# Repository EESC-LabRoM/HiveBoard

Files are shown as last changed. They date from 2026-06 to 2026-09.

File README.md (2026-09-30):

# HiveBoard

<p align="center">
  <picture>
    <source media="(prefers-color-scheme: dark)" srcset="Images/HIVEBOARD_logo_dark.png">
    <source media="(prefers-color-scheme: light)" srcset="Images/HIVEBOARD_logo_light.png">
    HiveBoard logo
  </picture>
</p>

[Project website](https://hiveboard-bench.github.io) · [Documentation](https://hiveboard-bench.github.io/hivedocs/) · [Evaluation Runner](https://hiveboard-bench.github.io/hivedocs/benchmark/evaluation-runner) · [Demonstration video](https://youtu.be/kaYB_Oc64nA)

HiveBoard is a modular, 3D-printable benchmark of industrial mechanisms for robotic and prosthetic manipulation. Its attachments require constrained motions such as valve rotation, threading, key insertion, and drawer opening and closing.

A seven-cell honeycomb base accepts interchangeable attachments through a shared press-fit interface. The same board and protocol can be used to evaluate robot grippers, dexterous hands, teleoperated manipulators, and worn prosthetic hands.

This repository contains the printable parts, CAD models, articulated simulation assets, evaluation protocol, and trial templates.

## Getting started

1. Read the [printing guide](https://hiveboard-bench.github.io/hivedocs/hardware/printing) and the recommended settings below.
2. Print one honeycomb cell and one attachment base to check the press fit before printing the full set.
3. [Assemble and mount the board](https://hiveboard-bench.github.io/hivedocs/hardware/assembly). Check that each mechanism moves freely and each attachment remains seated.
4. Read the [evaluation protocol](Documentation/PROTOCOL.md), including familiarization, success criteria, timeouts, and counting conventions.
5. Record **five trials for each of the 13 conditions (65 trials total)** using the [Evaluation Runner](https://hiveboard-bench.github.io/hivedocs/benchmark/evaluation-runner) or the [CSV](Documentation/trials.csv) / [XLSX](Documentation/trials.xlsx) template.

The documentation and Evaluation Runner are maintained in [`docs/` in the project website repository](https://github.com/hiveboard-bench/hiveboard-bench.github.io/tree/main/docs).

## Board and attachments

<p align="center">
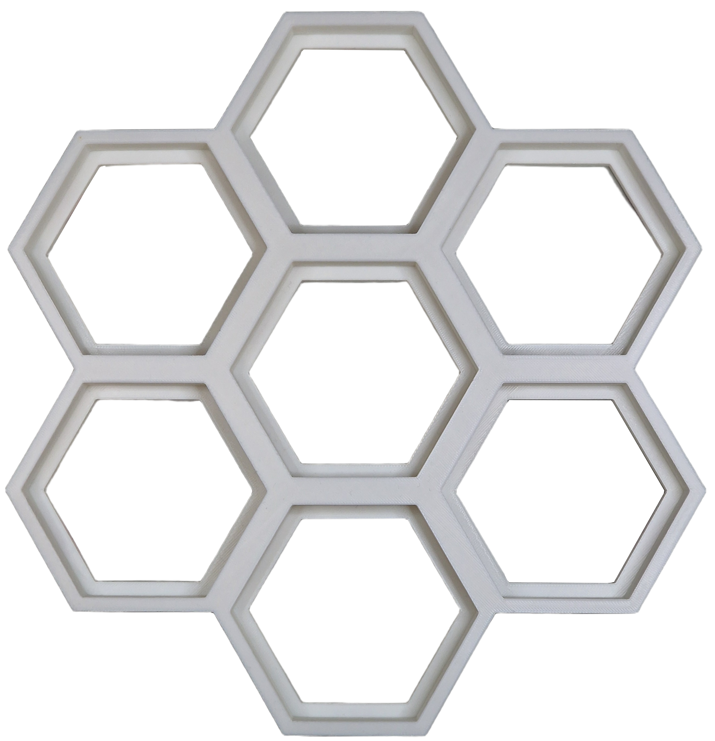
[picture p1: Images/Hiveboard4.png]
HiveBoard honeycomb base with mounted mechanisms
  
</p>

HiveBoard has 12 attachment designs evaluated in 13 conditions. The ball valve is evaluated without and with a friction ring, giving two conditions for the same attachment design. Attachments share the same mounting geometry. The shock absorber occupies two adjacent cells. The ball valve is evaluated in two configurations: without a friction ring and with a ring fitted.

<p align="center">
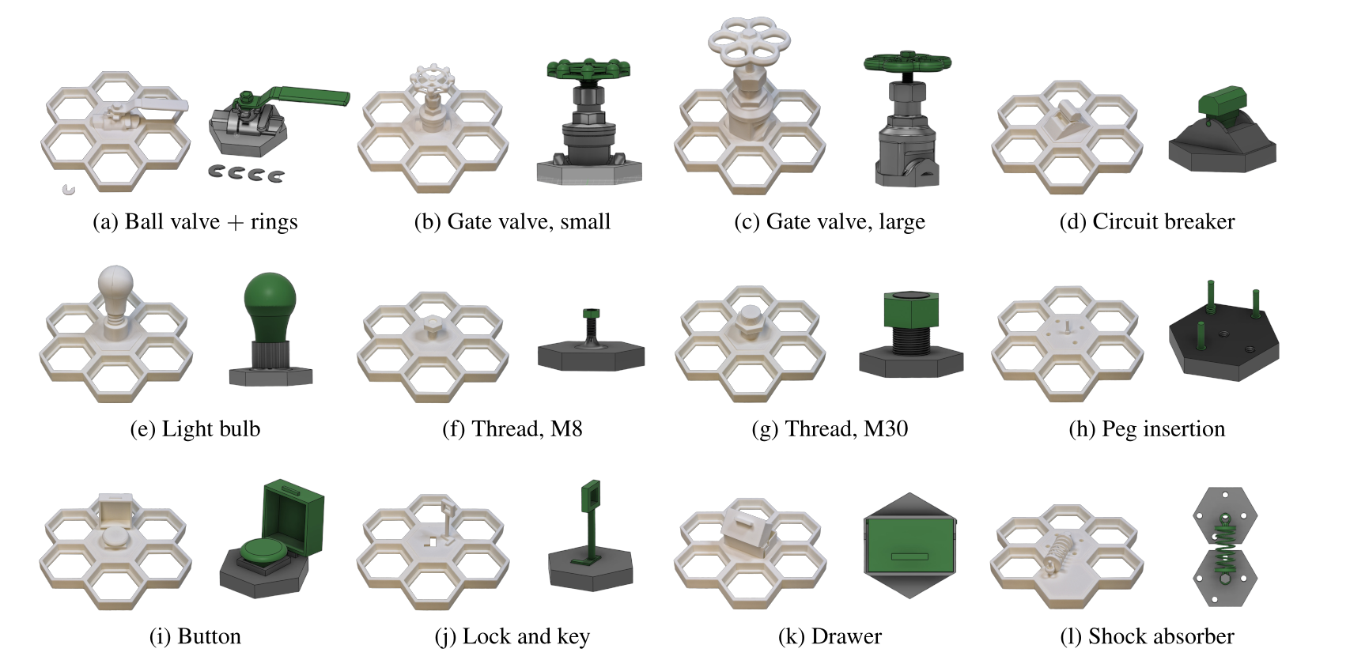
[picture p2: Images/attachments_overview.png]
HiveBoard mechanisms shown on the base and as individual renders
  
</p>

| Category | Attachment | Task |
|---|---|---|
| Torque | Ball valve | Rotate the lever 90° from closed to open |
| Torque | Ball valve + ring | Complete the same rotation with the ring fitted |
| Torque | Gate valve (small) | Rotate the stem one full turn |
| Torque | Gate valve (large) | Rotate the stem one full turn |
| Torque | Circuit breaker | Move the toggle to the opposite state and hold it |
| Precision | Light bulb | Thread the bulb until seated |
| Precision | Thread (M8) | Thread the bolt along the available length |
| Precision | Thread (M30) | Thread the bolt along the available length |
| Precision | Peg insertion | Align and thread the free 8 mm peg into the socket until seated |
| Composed assembly | Button | Open the cover and press the button |
| Composed assembly | Lock and key | Grasp the key, insert it vertically, and turn it to unlock |
| Composed assembly | Drawer | Grasp the handle, pull the drawer open, and push it closed |
| Composed assembly | Shock absorber | Grasp the loose part, align its hole with the pin, and insert the part fully onto the pin |

The friction-ring accessory includes four rings with different rotational resistance. Record the configuration used. The gate-valve criterion is **one full turn of the stem**; full travel depends on the printed thread pitch. For composed assembly tasks, record the last completed stage as well as the overall outcome.

See [the protocol](Documentation/PROTOCOL.md) for timeouts and stage definitions, and [Terminology](Documentation/TERMINOLOGY.md) for task names and trial identifiers.

## ArUco cell

The optional [ArUco cell](CAD/ArUco%20Cell/) provides a visual reference for board localization and alignment between physical and simulated scenes. Print the base in white PLA and the marker insert in black PLA, fit the parts together, and optionally glue the mating surfaces. The folder includes the two printable parts, an assembled model, a CAD reference image, and printing and assembly instructions.

## Recommended 3D printing settings

Use PLA and a consumer-grade FDM printer. A **300 × 300 mm build area** accommodates the complete honeycomb base without splitting it. Thread test pieces are included in [`STL/Threads/`](STL/Threads/) for checking print tolerances before producing the complete mechanisms.

Detailed assembly and printing instructions are available in the [attachment-specific printing guide (PDF)](https://github.com/user-attachments/files/29721347/HiveBoard.-.Module-Specific.Instructions.1.pdf).

### PLA profile

| Setting | Value |
|---|---|
| Material | PLA |
| Nozzle diameter | 0.4 mm |
| Layer height | 0.20 mm |
| Wall count | 4 |
| Top / bottom layers | 5 / 5 |
| Infill | 15–30%, according to part type |
| Print speed | 50 mm/s |
| Nozzle temperature | 200–220 °C |
| Bed temperature | 50–60 °C |
| Cooling fan | 100% |
| Supports | Only where required |
| Bed adhesion | Skirt or brim |

### Infill

| Part type | Infill |
|---|---|
| Base structure | 20% |
| Mechanical parts | 25% |
| Torque components | 30% |
| Threads | 25% |
| Decorative covers | 15% |

### Orientation

| Component | Orientation |
|---|---|
| Threads and screws | Vertical |
| Nuts | Flat |
| Valves | Handle up |
| Drawer | Largest face on the bed |
| Pegs | Vertical |
| Shock absorber parts | Sideways |

Remove stringing and support material, check mating surfaces, and test the threads by hand. Record sanding, lubrication, and dimensional adjustments with the evaluation. Inspect attachment seating before each session and after any displacement or damage.

## Evaluation and trial records

A complete evaluation contains **65 recorded trials**, including separate five-trial blocks for the two ball-valve configurations. Keep the platform configuration and control interface consistent within the recorded trial blocks.

For each trial, record:

- outcome: `success`, `fail`, `timeout`, or `safety_stop`;
- completion time in decimal seconds, for successful trials only;
- attempts counted from 1 and regrasps counted from 0;
- prehensile or non-prehensile strategy;
- last completed stage for composed assembly tasks; and
- one dominant failure cause for unsuccessful trials.

Use [`HOW_TO_FILL_TRIALS.md`](Documentation/HOW_TO_FILL_TRIALS.md) for the column definitions and allowed failure causes. Preserve trials involving broken or displaced parts and describe the event in `notes`.

### Browser-based evaluation

The [Evaluation Runner](https://hiveboard-bench.github.io/hivedocs/benchmark/evaluation-runner) displays task instructions and example videos, provides a countdown and timer, and exports the trial records. Begin the first commanded task motion when the countdown reaches zero. The evaluator determines whether the success criterion has been met.

Record every trial with an external camera, keeping the board, end-effector, and final task state visible. Once all 65 trial entries and required setup details are complete, the runner generates a results ZIP with the CSV, platform description, manifest, session backup, and recording filenames.

Attach the setup photograph in the runner or add it to the extracted ZIP as `setup.jpg`. Add the 65 recordings to `videos/` using the generated filenames. The runner saves records locally and does not upload submissions to the organizers.

## Simulation assets

[`Simulation/`](Simulation/) contains URDF and USD assets, visual and collision meshes, joint definitions, and nominal physical properties. The mechanisms use revolute, continuous, and prismatic joints. Threaded motion is represented by coupled rotation and translation; drawer, lock, and shock-absorber articulation is provided in the USD assets.

Friction, mass, and inertia are nominal values. Check joint motion, collision geometry, and physical parameters in the simulator used for an experiment, and report any parameter overrides.

Isaac Lab environments and training code are maintained separately in [EESC-LabRoM/isaaclab-hiveboard](https://github.com/EESC-LabRoM/isaaclab-hiveboard). See the [simulation documentation](https://hiveboard-bench.github.io/hivedocs/simulation/assets) for asset usage and the [Isaac Lab guide](https://hiveboard-bench.github.io/hivedocs/simulation/isaac-lab) for installation and commands.

## Reported evaluations

HiveBoard has been evaluated at four laboratories using:

| Platform | Control |
|---|---|
| Boston Dynamics Spot with Spot Arm | Native tablet teleoperation |
| LeRobot SO-101 | Leader–follower teleoperation |
| ANYbotics ANYmal with DynaArm | Virtual-reality controllers |
| Macao prosthetic hand | Worn on the operator's forearm |

Each platform ran all 65 trials. Results and demonstration videos are available on the [project website](https://hiveboard-bench.github.io). The original trial logs are held by the contributing laboratories and are not distributed in this repository.

## Repository contents

| Directory | Contents |
|---|---|
| [`STL/`](STL/) | Printable parts and thread test pieces |
| [`CAD/`](CAD/) | Source geometry and mesh exports |
| [`Simulation/`](Simulation/) | Articulated assets and meshes |
| [`Documentation/`](Documentation/) | Protocol, logging instructions, and CSV/XLSX templates |
| [`Images/`](Images/) | Photographs, logos, and renders |

For a new attachment, reuse the mounting interface and document its initial state, success criterion, timeout, and reset procedure. See [Adding an attachment](https://hiveboard-bench.github.io/hivedocs/guides/new-attachment).

## Citation

If you use HiveBoard in your research, cite the project paper:

```bibtex
@article{hiveboard2026,
  title   = {HiveBoard: An Open, Modular, 3D-Printed Benchmark of Industrial Mechanisms
             for Robotic and Prosthetic Manipulation},
  author  = {Godoy, Ricardo V. and de Souza, Enzo F. and de Lange, Rudy De-Xin and
             Negri, Juliano and Marsicano, Jo\~{a}o A. and van Halst, Victor and
             Elanjimattathil Vijayan, Aravind and Capezzuto, Gianluca and
             Angarola, Matheus P. and Tommaselli, Felipe A. G. and Milazzo, Giuseppe and Baptista, Rafael R. and
              van Berge, Meiko Adriana and Bezerra, Ranulfo and Lahr, Gustavo J. G. and Ferrari Gerez, Lucas and
              Bicchi, Antonio and Becker, Marcelo},
  journal = {Under review},
  year    = {2026},
  url     = {https://github.com/EESC-LabRoM/HiveBoard}
}
```

## License

This project is intended for research, educational, and prototyping purposes.

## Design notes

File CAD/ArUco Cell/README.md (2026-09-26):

# ArUco cell

The ArUco cell provides a visual reference for locating HiveBoard in camera images. It can support board-pose estimation and alignment of physical and simulated scenes once the marker dimensions and its placement on the board are known.

The cell has two interlocking parts, printed separately in white and black PLA. The white base forms the hexagonal support and the white regions of the marker. The black insert completes the marker pattern. The parts fit together and can be glued after checking their alignment.

This is an optional accessory. The benchmark evaluation remains 13 conditions with five trials per condition.

## Files

| File | Purpose | Material |
|---|---|---|
| [aruco_cell_base_white.obj](aruco_cell_base_white.obj) | Hexagonal base and white marker regions | White PLA |
| [aruco_cell_marker_black.obj](aruco_cell_marker_black.obj) | Black marker insert | Black PLA |
| [aruco_cell_assembly.obj](aruco_cell_assembly.obj) | Assembled reference with both parts in position | White and black |

Keep each OBJ beside its matching MTL file. The MTL files assign the display colors. Choose the corresponding filament when slicing each physical part. The assembly OBJ shows the intended fit and orientation.

These are mesh exports. Vertex positions, faces, and exported scale are preserved from the supplied files. Filenames, object groups, and material names have been standardized in English, and the OBJ material links have been updated.

## Printing and assembly

1. Import the white base and black insert into the slicer as separate parts. Set the import units to centimetres, or apply a scale factor of 10 if the slicer interprets OBJ coordinates as millimetres. Apply the same scale to both parts and verify an assembled width of 88.1 mm.
2. Print the base in white PLA and the insert in black PLA. Use the repository's recommended PLA profile as a starting point and inspect the mating surfaces for stringing or excess material.
3. Fit the two parts together in the orientation shown in the assembly model. Check that the marker pattern is complete and the insert is fully seated.
4. If permanent assembly is required, apply a small amount of PLA-compatible adhesive to the mating surfaces. Keep adhesive away from the visible marker face. Let it cure before mounting.
5. Seat the assembled cell in the honeycomb base and check that it remains fixed. Keep the marker visible to the camera during use.

## Dimensions and marker configuration

The designer confirmed an overall width of **88.1 mm**. The OBJ coordinates therefore correspond to centimetres. The files retain their original coordinates.

| Dimension | Nominal size |
|---|---|
| Assembly bounding box | 88.1 × 76.297 × 22.0 mm |
| Outer black marker square | 47.505 mm per side |

For a millimetre-based importer, multiply the OBJ coordinates by 10. For a metre-based simulator, multiply them by 0.01. Check the imported dimensions before printing or using the model in simulation.

The marker was generated with [chev.me/arucogen](https://chev.me/arucogen/) using **4×4 (50, 100, 250, 1000)** and **marker ID 0**. Configure the detector with **OpenCV `DICT_4X4_50`, ID `0`**. This ID has the same bit pattern in `DICT_4X4_50`, `DICT_4X4_100`, `DICT_4X4_250`, and `DICT_4X4_1000`, which share the same underlying marker list in [OpenCV](https://github.com/opencv/opencv/blob/4.x/modules/objdetect/src/aruco/aruco_dictionary.cpp). Verify detection on the printed part. For pose estimation, measure the square marker side from the outer edges of its black border and use calibrated camera parameters. Record the marker's location and orientation relative to the board so that its estimated pose can be converted to a board pose.

Record the dictionary, marker ID, measured marker side length, model scale, and marker-to-board transform with each setup. Detection accuracy and physical-to-simulation alignment need to be measured in the intended camera and lighting configuration.

See the [OpenCV ArUco detection documentation](https://docs.opencv.org/4.x/d5/dae/tutorial_aruco_detection.html) for dictionary selection, detection, and pose estimation.

## Assembly model

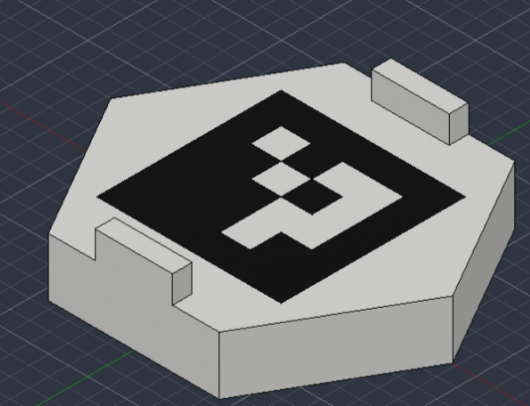
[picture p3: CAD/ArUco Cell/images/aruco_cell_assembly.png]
CAD view of the white hexagonal base and black marker insert


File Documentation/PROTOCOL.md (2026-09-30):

# HiveBoard: Data Collection Protocol

Use [Terminology](TERMINOLOGY.md) to match task names to trial identifiers and existing file names.

This document specifies the data each collaborating laboratory collects to validate HiveBoard, the modular dexterity board. The activity is operator-driven trials, robot-side performance characterization across attachments. Operators may control the manipulation system through a teleoperated arm or through a wearable interface or exoskeleton that drives a gripper or hand directly.

The objective is to demonstrate that the board is functional, reproducible, and discriminative across attachments and platforms. The protocol does not rank platforms against each other and does not characterize control interfaces or operators.

**Project resources:**
- Repository (STL, CAD, simulation assets, this protocol, trial logging template): https://github.com/EESC-LabRoM/HiveBoard
- Project page: https://hiveboard-bench.github.io
- Demonstration video (board walk-through and example trials): https://youtu.be/kaYB_Oc64nA

---

## 1. Materials

- One printed HiveBoard base.
- One full set of attachments across all three categories (torque, precision, composed assembly), including the four-piece friction ring accessory set for the ball valve.
- A manipulation system, consisting of an end-effector (gripper or hand) plus a control interface. The control interface may be:
  - a teleoperated robotic arm with a standard interface (e.g., SpaceMouse, leader arm, VR controller), or
  - a wearable interface or exoskeleton driving the end-effector directly.

## 2. Printing Specifications

The canonical print profile lives in the project README. Summary, for convenience:

- **Material:** PLA, 1.75 mm filament.
- **Nozzle:** 0.4 mm.
- **Layer height:** 0.20 mm.
- **Walls:** 4 perimeters.
- **Top / bottom layers:** 5 / 5.
- **Print speed:** 50 mm/s.
- **Nozzle temperature:** 200 to 220 °C.
- **Bed temperature:** 50 to 60 °C.
- **Cooling:** 100%.
- **Adhesion:** skirt or brim.
- **Supports:** only where required.

**Infill, per part type:**

| Part type | Infill |
|---|---|
| Base structure | 20% |
| Mechanical parts | 25% |
| Torque components | 30% |
| Threads | 25% |
| Decorative covers | 15% |

**Print orientation:**

| Component | Orientation |
|---|---|
| Threads / screws | vertical |
| Nuts | flat |
| Valves | handle up |
| Drawer | flat on the largest face |
| Pegs | vertical |
| Shock absorber parts | sideways |

**Post-processing.** Remove stringing and check that mating surfaces seat fully before testing. Minor sanding of threaded surfaces may improve performance when printer calibration produces tight tolerances. If sanding is applied to any attachment, record it in the trial `notes` column.

## 3. Physical Setup

1. Fix the HiveBoard base to a rigid surface within the operator's working volume. The base may be mounted horizontally on a tabletop or vertically on a fixture. State which one in `platform.md`, since a vertical mount changes the approach direction for every attachment and makes press-fit release more likely.
2. Insert the attachments into their designated cells. Each attachment seats by press-fit; verify all attachments are fully seated before starting trials.
3. Position the manipulation system so that all attachments are reachable without base repositioning during a trial.
4. Photograph the setup and store the image as `setup.jpg`.

## 4. Trial Procedure

HiveBoard has 12 attachment designs evaluated in 13 conditions. The ball valve is evaluated without and with a friction ring, giving two conditions for the same attachment design.

For each `(platform, condition)` pair:

1. **Familiarization.** Run unrecorded practice trials until completion times stabilize. Record only after three consecutive practice trials complete within 20% of each other or within the timeout, whichever comes first.
2. **Recorded trials.** Run **5 recorded trials** per condition. The end-effector starts each trial from the same neutral pose for a given platform.
3. **Trial start.** Begin timing when the operator initiates the first commanded motion toward the attachment.
4. **Trial end.** Stop timing when the success criterion is met, when a safety event occurs, or when the timeout is reached.
5. **Reset.** Return the attachment to its starting state between trials. Re-seat the attachment in its cell if displaced.

The ball valve is run as two separate sets of 5 trials: once without the friction ring (`valve_ball`) and once with the ring fitted (`valve_ball_ring`).

No scripted assistance, replanning, or per-trial parameter tuning is permitted during recorded trials. A restarted approach within a trial counts as another attempt. Count a regrasp only when the end-effector releases the part and grasps it again. The initial grasp is not a regrasp. Attempts and regrasps are separate counts; neither starts a new trial.

6. **Broken or displaced parts.** If a printed part breaks or leaves its cell during a trial, record the trial as it stood, describe the damage in the `notes` column, and reprint or reseat the part before continuing. Do not silently rerun the trial. Printed mechanisms have failed under jittering or high-gain command signals in previous sessions, and those events are part of the result.

## 5. Per-Attachment Success Criteria and Timeouts

**Torque category**

| Attachment | Success criterion | Timeout |
|---|---|---|
| Ball valve | Handle rotated 90° from closed to open | 60 s |
| Ball valve + ring | Handle rotated 90° from closed to open with the ring fitted | 90 s |
| Gate valve (small) | Stem rotated one full turn from the closed position | 90 s |
| Gate valve (large) | Stem rotated one full turn from the closed position | 120 s |
| Circuit breaker | Toggle moved from one state to the other and held | 60 s |

**Precision category**

| Attachment | Success criterion | Timeout |
|---|---|---|
| Light bulb | Bulb fully threaded until seated | 120 s |
| Thread (M8) | Bolt fully threaded along available length | 120 s |
| Thread (M30) | Bolt fully threaded along available length | 120 s |
| Peg insertion | Free peg threaded into the empty socket until it seats | 120 s |

The gate valve criterion is one full turn of the stem, not travel from fully closed to fully open. A platform that can turn the stem once can repeat the motion, and the number of turns to full travel depends on the printed thread pitch, so full travel is not comparable across prints. If your trials ran to full travel, report the time to the first complete turn and note it in the `notes` column.

**Composed assembly category (stage-wise scoring)**

These attachments are scored at sub-task granularity. Record the last completed stage within the timeout.

| Attachment | Stages | Timeout |
|---|---|---|
| Button | (1) Open the cover (2) Press the button until actuation | 60 s |
| Lock and key | (1) Grasp key (2) Insert key vertically (3) Rotate to unlock | 180 s |
| Drawer | (1) Grasp handle (2) Pull open (3) Push closed | 120 s |
| Shock absorber | (1) Grasp the loose part (2) Align its hole with the pin (3) Insert the part fully onto the pin | 180 s |

A trial is a full success only if all stages complete within the timeout. Partial completions are recorded by their last completed stage in the `stage_reached` column.

## 6. Data to Log per Trial

Each trial fills one row of `trials.csv` (template provided alongside this protocol). See `HOW_TO_FILL_TRIALS.md` for column-by-column instructions.

### Logging conventions

These conventions exist because logs returned from different laboratories have disagreed on all five points, which leaves the columns incomparable until they are reconciled by hand.

| Column | Convention |
|---|---|
| `completion_time_s` | Decimal seconds, as a plain number. Not milliseconds, not a text string, not a clock time, not a date. Write `12.9`, not `12923`, not `12.9 s`, not `timeout`. Leave the cell empty when the outcome is not `success`. |
| `n_attempts` | Discrete attempts at the task within the trial, counted from 1. An attempt ends when the operator abandons the current approach and starts over. Corrective motions inside one continuous approach are not separate attempts. |
| `n_regrasps` | Times the end-effector released the part and closed on it again, counted from 0. A trial with one grasp and no release is 0. A platform that cannot regrasp records 0. |
| `stage_reached` | The number of the last stage the trial completed, from 0 to 3. A successful trial reaches its final stage. A trial that never completed stage 1 is 0. Fill only for the composed assembly attachments. |
| `strategy` | `prehensile` when the end-effector closed around the part and held it, `non_prehensile` when the part was driven by pushing or pressing, or by a finger or jaw entered into an opening without an enclosing grip. |

Fill `n_attempts`, `n_regrasps`, and `strategy` on unsuccessful trials as well. A failed trial still had attempts, and how a platform approached a part it could not complete is as informative as how it approached one it could.

For every trial whose outcome is `fail`, `timeout`, or `safety_stop`, record the dominant failure cause in the `failure_cause` column using this closed vocabulary:

| Cause | Meaning |
|---|---|
| `grasp_geometry` | The end-effector cannot engage the part in a stable grasp (shape, size, or access mismatch). |
| `kinematic_limit` | The platform cannot produce the motion the task requires (e.g., clean rotation about an axis). |
| `perception` | The operator could not see or judge alignment well enough to complete the task. |
| `slip` | A grasp was acquired but lost during execution. |
| `force_limit` | The grasp or actuation force the platform can produce is insufficient for the task, even though the grasp and the motion are otherwise correct (e.g., holding a screw against thread friction). |
| `control_precision` | The available control resolution was too coarse for the clearance or force the task requires. |
| `other` | None of the above; describe in `notes`. Use this for a trial ended by a broken printed part. |

Pick the single dominant cause per trial. Leave the column blank on `success` rows. The closed vocabulary is what makes failure modes comparable across laboratories, so use `other` plus a note only when nothing else fits.

Alongside `trials.csv`, each lab provides:

- `setup.jpg`, photograph of the physical setup.
- `platform.md`, short description of the manipulation system: end-effector (gripper or hand), control interface (teleoperated arm or wearable), board mounting orientation, and any relevant control mode or calibration notes.

## 7. Submission

Each collaborating lab returns a single archive containing:

- `trials.csv`
- `setup.jpg`
- `platform.md`

### Reproducibility checklist

- [ ] All attachments printed with the specified PLA profile and per-part-type infill.
- [ ] Each attachment seats fully in the base before trials begin.
- [ ] Familiarization completed for every attachment before recording.
- [ ] 5 recorded trials per condition, all logged in `trials.csv`. The ball valve appears twice, once without the friction ring and once with it.
- [ ] Timeouts enforced as specified.
- [ ] `failure_cause` filled from the closed vocabulary for every `fail`, `timeout`, and `safety_stop` row.
- [ ] `completion_time_s` in decimal seconds on every `success` row, and empty everywhere else.
- [ ] `n_attempts` counted from 1 and `n_regrasps` from 0, on failed rows as well as successful ones.
- [ ] `strategy` filled on every row.
- [ ] Any broken or reseated part described in `notes`.
- [ ] `setup.jpg` and `platform.md` included, with the board mounting orientation stated.
- [ ] No operator names or identifiers in any field.

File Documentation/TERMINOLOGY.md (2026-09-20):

# Terminology

Use the task names from Table 2 of the HiveBoard paper in instructions, figures, result tables, and interfaces. The table below maps those names to the identifiers used in trial records.

## Task names and identifiers

| Task name | Trial identifier (`attachment_id`) | Category |
|---|---|---|
| Ball valve | `valve_ball` | Torque |
| Ball valve + ring | `valve_ball_ring` | Torque |
| Gate valve (small) | `valve_gate_small` | Torque |
| Gate valve (large) | `valve_gate_large` | Torque |
| Circuit breaker | `circuit_breaker` | Torque |
| Light bulb | `light_bulb` | Precision |
| Thread (M8) | `thread_m8` | Precision |
| Thread (M30) | `thread_m30` | Precision |
| Peg insertion | `peg_insertion` | Precision |
| Button | `button` | Composed assembly |
| Lock and key | `lock` | Composed assembly |
| Drawer | `drawer` | Composed assembly |
| Shock absorber | `shock_absorber` | Composed assembly |

HiveBoard has 12 attachment designs evaluated in 13 conditions. The ball valve is evaluated without and with a friction ring, giving two conditions for the same attachment design. Ball valve + ring is the condition with the ring fitted. Record five trials for each of the 13 conditions, including separate blocks for Ball valve and Ball valve + ring.

The category headings are **Torque-based tasks**, **Precision-based tasks**, and **Composed assembly tasks**. In tables, use **Torque**, **Precision**, and **Composed assembly**. The abbreviation “Assembly” in existing templates and the paper's Table 2 refers to Composed assembly.

## Hardware, tasks, and evaluation

| Term | Meaning |
|---|---|
| Honeycomb base | The structure into which the attachments are mounted. |
| Attachment | A physical mechanism mounted on the base, such as the drawer or a gate valve. |
| Task | The operation performed on an attachment, with a specified starting state and success criterion. |
| Condition | A scored task configuration. The two ball-valve configurations are separate conditions. |
| Trial | One recorded execution of a task, ending at success, failure, timeout, or a safety stop. |
| Platform | The end-effector and the system that positions and commands it. |
| End-effector | The gripper, hand, or other terminal device that interacts with the attachment. |
| Control interface | The interface used to command the platform. Record the control mode or policy separately where relevant. |
| Asset | A digital file or model, such as CAD geometry, a mesh, URDF, or USD. Use “attachment” for the physical mechanism. |
| Attempt | A discrete approach to the task within a trial; count from 1. Abandoning an approach and starting another adds one attempt. |
| Regrasp | A release followed by grasping the part again; count from 0. An initial grasp is not a regrasp. |
| Last completed stage | The highest completed stage of a composed assembly task, recorded as `stage_reached`; 0 means no stage was completed. |
| Dominant failure cause | The single cause recorded in `failure_cause` for an unsuccessful trial. |

## Existing names in files

Older labels and file paths may use the names below. They refer to the same attachments; descriptive details such as the button cover or the threaded peg remain part of the task instructions.

| Existing label or filename term | Task name |
|---|---|
| Ball valve with friction ring | Ball valve + ring |
| Small gate valve; Valve Gate (Small) | Gate valve (small) |
| Large gate valve; Valve Gate (Large) | Gate valve (large) |
| Light bulb socket; light bulb and socket; `Lamp/` | Light bulb |
| M8 threaded fastener; Thread M8 | Thread (M8) |
| M30 threaded fastener; Thread M30 | Thread (M30) |
| Threaded peg insertion; Peg Insertion Plate | Peg insertion |
| Covered button; Hidden Push Button | Button |
| `Key/` | Lock and key |
| Sliding Drawer; `box` in image/video filenames | Drawer |
| `spring` in image/video filenames | Shock absorber |

Keep existing identifiers, paths, and data fields unchanged. For example, `lock` remains the trial identifier for Lock and key, `light_bulb` remains the identifier for Light bulb, and `control_method` remains the runner's stored field for the control interface. The CSV outcome `fail` is displayed as “Failure” in the runner.

Thread (M14) is available in the 3D viewer but is not one of the 13 scored conditions.

See [the protocol](PROTOCOL.md) for task criteria and [the logging instructions](HOW_TO_FILL_TRIALS.md) for counting conventions.

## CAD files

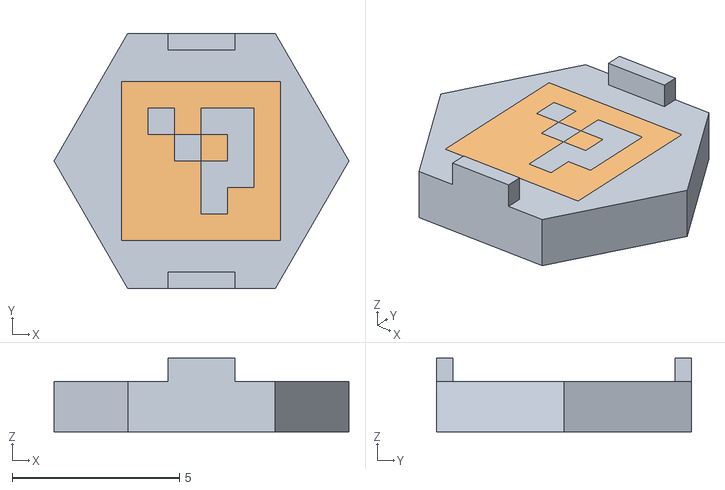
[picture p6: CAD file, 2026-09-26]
CAD/ArUco Cell/aruco_cell_assembly.obj
8.81 x 7.63 x 2.20
aruco_cell_base_white
aruco_cell_marker_black

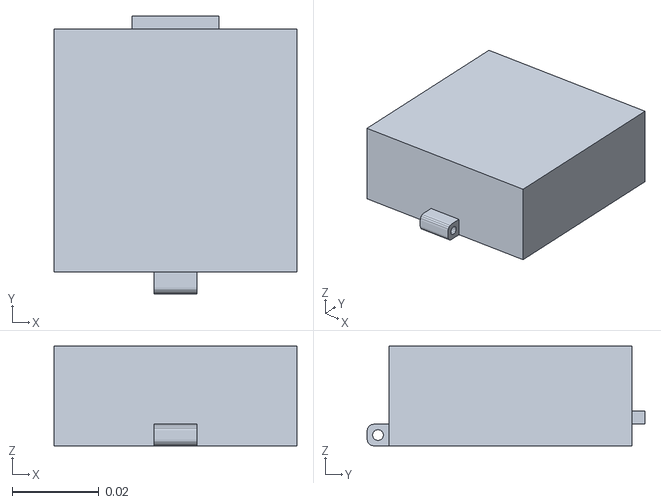
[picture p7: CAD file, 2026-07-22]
Simulation/Button/meshes/tn__Tampa1_dC_Corpo1_Mesh.obj
0.056 x 0.064 x 0.023

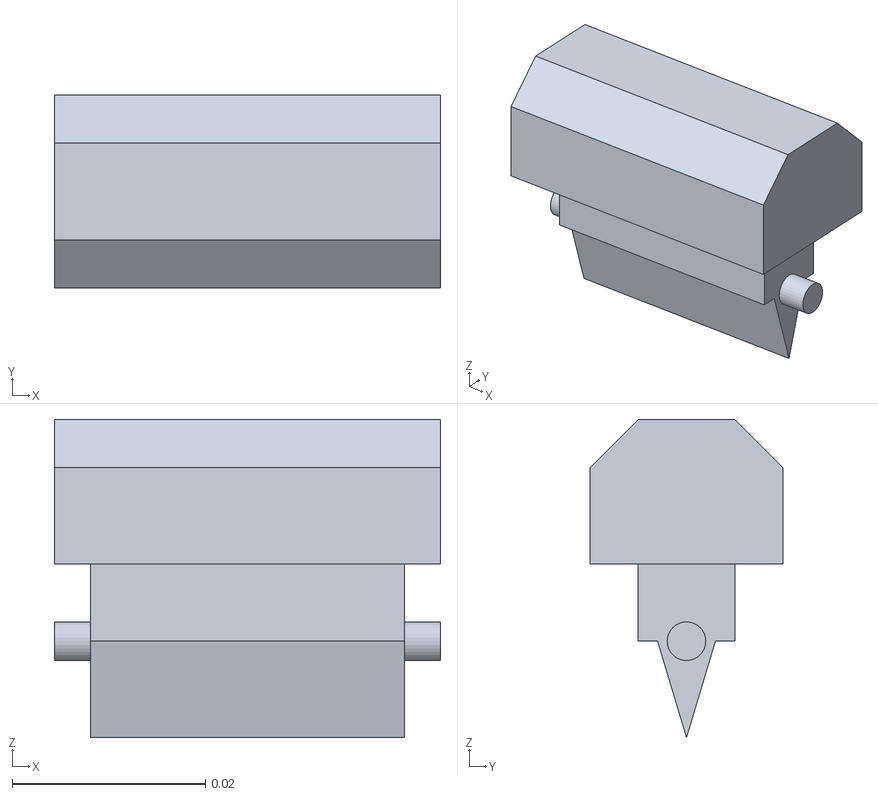
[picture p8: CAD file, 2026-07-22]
Simulation/Circuit Breaker/meshes/tn__Alavanca1_zH_Corpo1_Mesh.obj
0.04 x 0.02 x 0.033

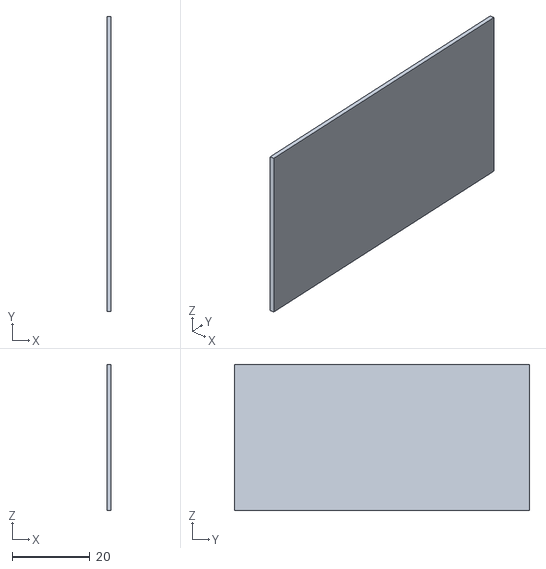
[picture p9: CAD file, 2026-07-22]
Simulation/Drawer/meshes/simple_colliders_Cube_01.obj
1 x 75.7 x 37.6

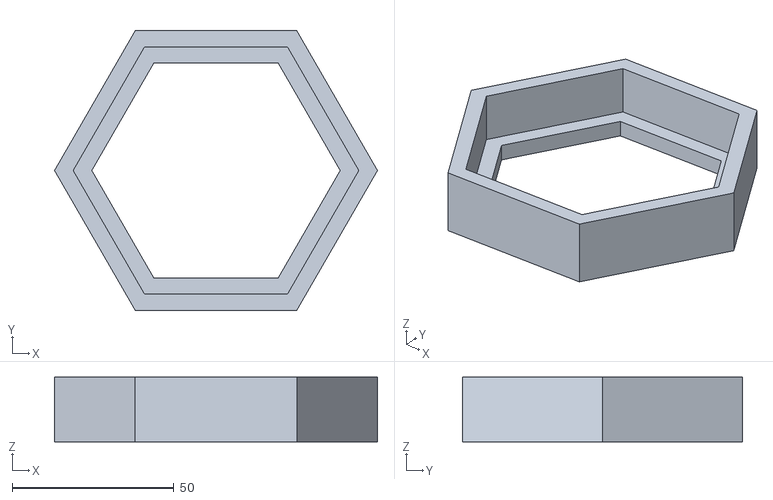
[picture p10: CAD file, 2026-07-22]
Simulation/Honeycomb/meshes/tn__Hexagono_Suporte3_bX0_Corpo1_Mesh.obj
100.0 x 86.6 x 20.0

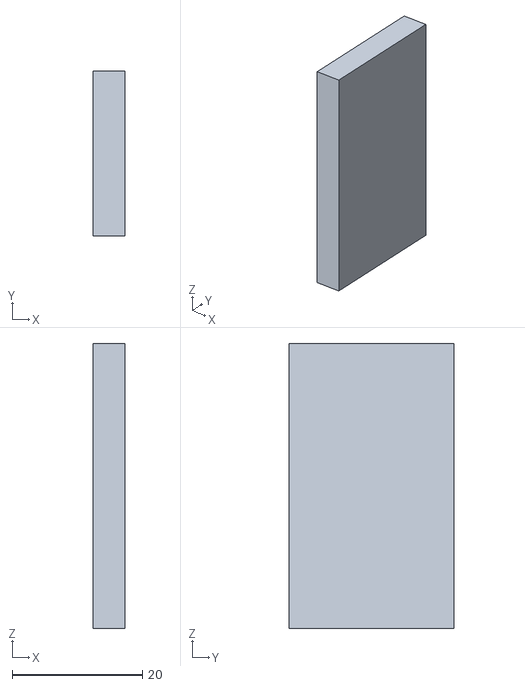
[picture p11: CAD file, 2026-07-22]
Simulation/Key/meshes/Key_Base_pivot_Corpo1_simple_colliders_Cube_01.obj
4.93 x 25.4 x 43.8

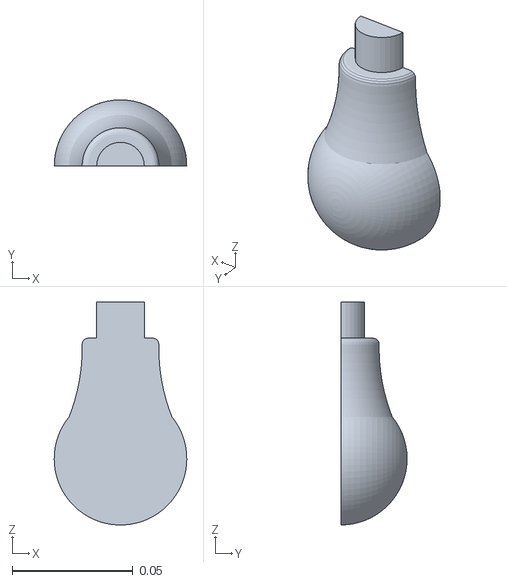
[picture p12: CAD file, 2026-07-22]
Simulation/Lamp/meshes/tn__Corpo11_j7m1J_Mesh.obj
0.055 x 0.0275 x 0.0925

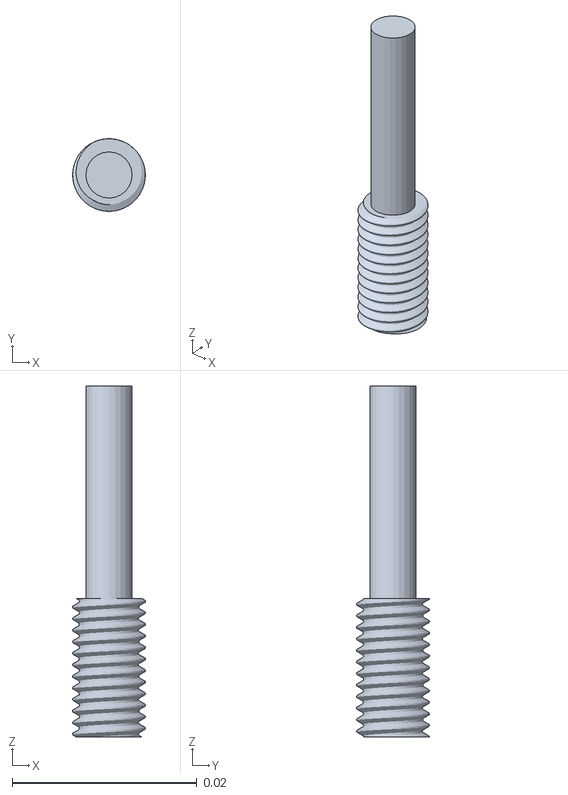
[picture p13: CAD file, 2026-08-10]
Simulation/Peg Insertion/meshes/Al__a_Corpo1.obj
0.00786 x 0.00787 x 0.038

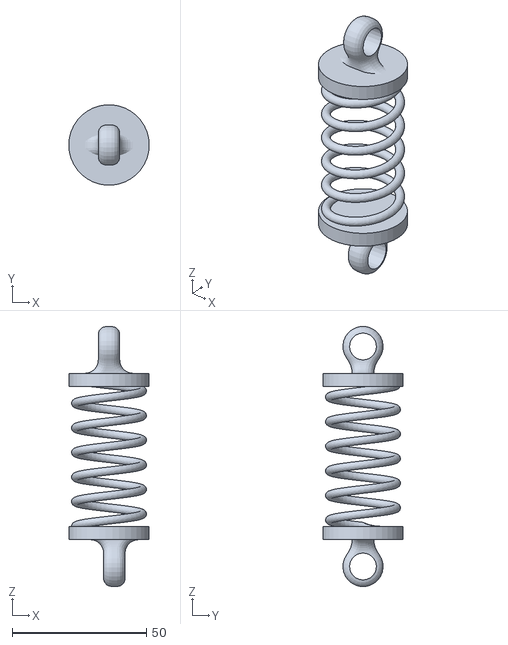
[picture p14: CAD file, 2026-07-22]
Simulation/Shock Absorber/meshes/Corpo3.obj
30.0 x 29.9 x 96.9

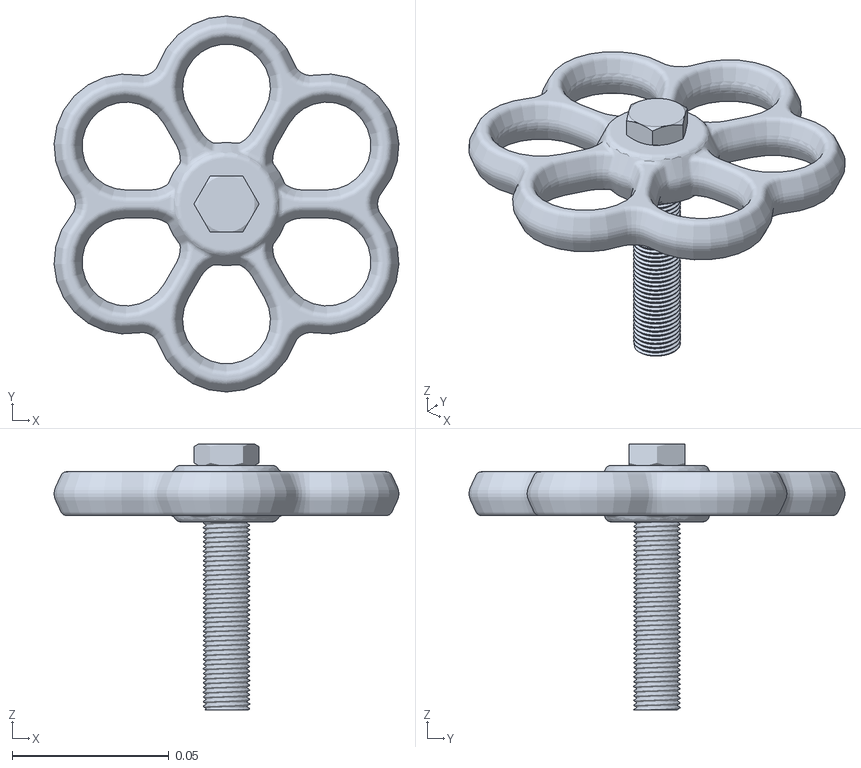
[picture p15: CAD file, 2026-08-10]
Simulation/Valves/Gate Valve/High Torque Valve/meshes/Corpo1__1_.obj
0.11 x 0.12 x 0.0848

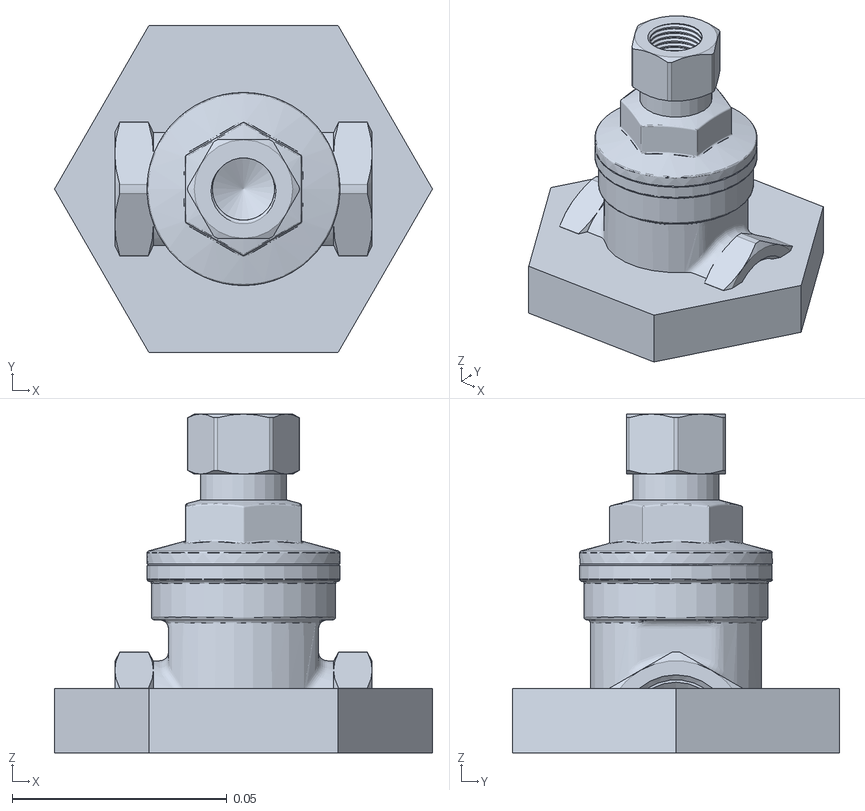
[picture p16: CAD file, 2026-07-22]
Simulation/Valves/Gate Valve/Small Valve/meshes/Mesh_1.obj
0.0881 x 0.0763 x 0.079

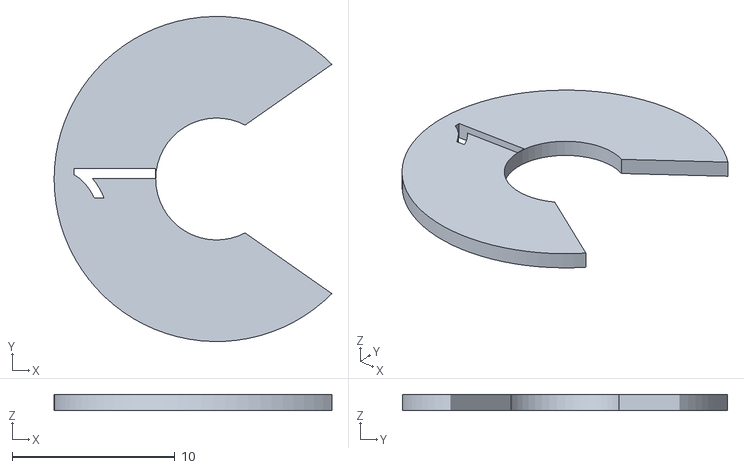
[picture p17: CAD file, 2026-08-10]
Simulation/Valves/Lever Valve/Ball Valve/meshes/Corpo4_Mesh.obj
17.1 x 20.0 x 1.00

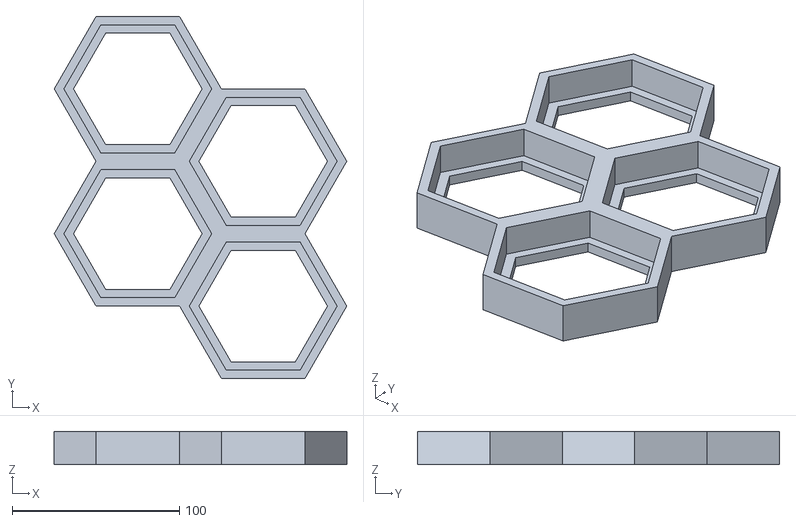
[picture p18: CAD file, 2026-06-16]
STL/Honeycomb/Honeycomb_Panel_S.stl
175.0 x 216.5 x 20.0

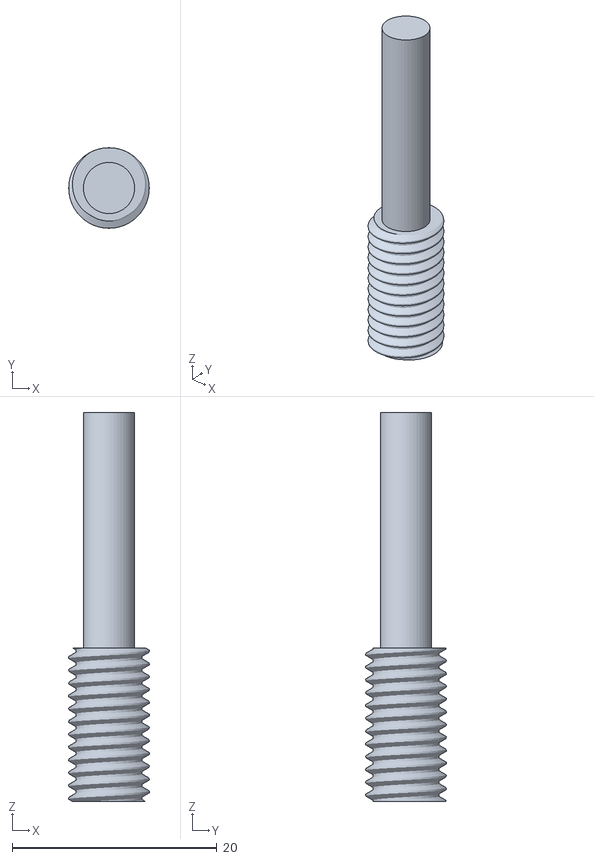
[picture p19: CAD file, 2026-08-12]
STL/Peg Insertion/peg.stl
7.87 x 7.87 x 38.0

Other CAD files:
CAD/ArUco Cell/aruco_cell_base_white.obj
Simulation/Button/meshes/tn__corpo1_dC_Corpo1_Mesh.obj
Simulation/Circuit Breaker/meshes/tn__corpo1_dC_Corpo1_Mesh.obj
Simulation/Drawer/meshes/right_Guide_Cube_02.obj
CAD/ArUco Cell/aruco_cell_marker_black.obj
STL/Honeycomb/Honeycomb_Panel_M.stl
STL/Peg Insertion/Base.stl
Simulation/Button/meshes/tn__botao1_dC_Corpo1_Mesh.obj
Simulation/Drawer/meshes/Cylinder.obj
Simulation/Drawer/meshes/Cylinder_02.obj
Simulation/Drawer/meshes/left_Guide_Cube.obj
Simulation/Drawer/meshes/left_Guide_Cube_01.obj
Simulation/Drawer/meshes/left_Guide_Cube_02.obj
Simulation/Drawer/meshes/left_Guide_Cube_03.obj
Simulation/Drawer/meshes/left_Guide_Cube_04.obj
Simulation/Drawer/meshes/right_Guide_Cube.obj
Simulation/Drawer/meshes/right_Guide_Cube_01.obj
Simulation/Drawer/meshes/right_Guide_Cube_03.obj
Simulation/Drawer/meshes/right_Guide_Cube_04.obj
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

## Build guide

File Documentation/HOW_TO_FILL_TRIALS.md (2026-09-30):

# How to fill `trials.csv`

The CSV is pre-populated with one row per trial, in the order trials should be run. Each block of 5 rows corresponds to one condition. See [Terminology](TERMINOLOGY.md) for the task names and trial identifiers.

**Do not change** `trial_id` or `attachment_id`. Fill the remaining columns as you run the trials.

For a video walk-through of the protocol see: https://youtu.be/kaYB_Oc64nA

## Columns to fill

| Column | What to enter |
|---|---|
| `lab_id` | Short identifier for your lab (e.g., `usp_crob`, `eth_rsl`, `iit_genoa`). Use the same value on every row. |
| `platform_id` | End-effector + control interface combination, lowercase, underscores. Examples: `franka_2f85` (Franka arm with Robotiq 2F-85, teleop), `ur5_robotiq_3f` (UR5 with Robotiq 3F), `anymal_arm_dynaarm`, `psyonic_ability_wearable` (Psyonic Ability Hand driven by a wearable interface). Use the same value on every row. |
| `date` | Trial date in `YYYY-MM-DD` format. |
| `outcome` | One of: `success`, `fail`, `timeout`, `safety_stop`. |
| `failure_cause` | **Required whenever outcome is not `success`.** One of: `grasp_geometry`, `kinematic_limit`, `perception`, `slip`, `force_limit`, `control_precision`, `other`. Pick the single dominant cause; see the quick reference below. Leave blank on `success` rows. |
| `completion_time_s` | **Decimal seconds** from trial start to success, as a plain number. Write `12.9`. Do not write milliseconds (`12923`), units (`12.9 s`), text (`timeout (120s+)`), or a date. **Leave blank** if outcome is not `success`. |
| `n_attempts` | Discrete attempts at the task within the trial, **counted from 1**. An attempt ends when the operator abandons the current approach and starts over. Corrective motions inside one continuous approach are not separate attempts. Fill this on unsuccessful trials too. |
| `n_regrasps` | Times the end-effector released the part and closed on it again, **counted from 0**. One grasp with no release is `0`, not `1`. A platform that cannot regrasp records `0`. Fill this on unsuccessful trials too. |
| `stage_reached` | **Only fill for composed assembly attachments** (button, lock, drawer, shock_absorber). The number of the **last stage completed**, from 0 to 3. A successful trial reaches its final stage. A trial that never completed stage 1 is `0`. Leave blank for all other attachments. |
| `strategy` | `prehensile` if the end-effector closed around the part and held it. `non_prehensile` if the part was driven by pushing or pressing, or by a finger or jaw entered into an opening without an enclosing grip. Fill on every row, successful or not. |
| `notes` | Free-form notes. ASCII only. No operator names. Record here any deviation from the success criterion, any sanding, and any part that broke or came loose. |

## Quick reference for failure causes

| Cause | Use when |
|---|---|
| `grasp_geometry` | The end-effector cannot engage the part in a stable grasp (shape, size, or access mismatch). |
| `kinematic_limit` | The platform cannot produce the motion the task requires (e.g., clean rotation about an axis). |
| `perception` | The operator could not see or judge alignment well enough to complete the task. |
| `slip` | A grasp was acquired but lost during execution. |
| `force_limit` | The platform cannot produce enough grasp or actuation force for the task, even though grasp and motion are otherwise correct. |
| `control_precision` | The control resolution was too coarse for the clearance or force the task requires. |
| `other` | Nothing above fits; explain in `notes`. |

## Quick reference for stage numbering

| Attachment | Stage 1 | Stage 2 | Stage 3 |
|---|---|---|---|
| Button (`button`) | Open the cover | Press the button | n/a |
| Lock and key (`lock`) | Grasp key | Insert key vertically | Rotate to unlock |
| Drawer (`drawer`) | Grasp handle | Pull open | Push closed |
| Shock absorber (`shock_absorber`) | Grasp loose part | Align its hole with the pin | Insert part fully onto pin |

Enter the number, not the stage name. A shock-absorber trial in which the loose part was grasped but its hole was never aligned with the pin is `1`. A trial in which the gripper never held the loose part is `0`. The loose part moves onto the pin, which stays in place.

## Quick reference for timeouts

The ball valve is run in two configurations: without the friction ring (`valve_ball`) and with it fitted (`valve_ball_ring`). Each configuration is a separate set of 5 trials, recorded as a separate condition.

| Attachment | Timeout |
|---|---|
| Ball valve (`valve_ball`) | 60 s |
| Ball valve + ring (`valve_ball_ring`) | 90 s |
| Gate valve (small) (`valve_gate_small`) | 90 s |
| Gate valve (large) (`valve_gate_large`) | 120 s |
| Circuit breaker (`circuit_breaker`) | 60 s |
| Light bulb (`light_bulb`) | 120 s |
| Thread (M8) (`thread_m8`) | 120 s |
| Thread (M30) (`thread_m30`) | 120 s |
| Peg insertion (`peg_insertion`) | 120 s |
| Button (`button`) | 60 s |
| Drawer (`drawer`) | 120 s |
| Lock and key (`lock`) | 180 s |
| Shock absorber (`shock_absorber`) | 180 s |

## Examples (for reference only, do not paste these into your CSV)

A torque attachment, mixed outcomes:

```
1,usp_crob,franka_2f85,valve_gate_small,2026-04-26,success,,34.2,1,0,,prehensile,
2,usp_crob,franka_2f85,valve_gate_small,2026-04-26,fail,slip,,3,2,,prehensile,handle slipped
3,usp_crob,franka_2f85,valve_gate_small,2026-04-26,timeout,control_precision,,4,3,,prehensile,
```

A composed assembly attachment with stage tracking:

```
56,usp_crob,franka_2f85,lock,2026-04-26,success,,142.3,2,1,3,prehensile,
57,usp_crob,franka_2f85,lock,2026-04-26,fail,slip,,5,4,2,prehensile,key dropped twice
```

## Common mistakes

Every entry below has appeared in a returned log and had to be reconciled by hand.

| Mistake | What to do instead |
|---|---|
| Times in milliseconds, or mixed milliseconds and seconds in the same column | One unit for the whole column, decimal seconds |
| `timeout (120s+)` in the time column | Leave the time blank and set the outcome to `timeout` |
| A date pasted into the time column by autofill | Format the column as plain number before filling |
| An outcome written into the `date` column | Keep every value in its own column |
| `n_regrasps` never below 1 | A single grasp with no release is `0` |
| `-` in `n_attempts` and `n_regrasps` on failed rows | Enter the counts; a failed trial still had attempts |
| Six rows for one condition, or a repeated `trial_id` | 5 rows per condition, 65 rows total, `trial_id` unchanged |
| `stage_reached` left blank on a failed composed assembly trial | Enter the last stage completed, `0` if none |
| A rerun after a part broke, logged as though nothing happened | Log the trial as it stood and describe the damage in `notes` |

## Before sending back

- All 65 data rows have `lab_id`, `platform_id`, `date`, and `outcome` filled.
- `failure_cause` is filled from the closed vocabulary for every row whose outcome is not `success`, and blank on `success` rows.
- `completion_time_s` is filled in decimal seconds for every `success` row and blank otherwise.
- `n_attempts`, `n_regrasps`, and `strategy` are filled on every row, failed rows included.
- `stage_reached` is filled only for `button`, `lock`, `drawer`, and `shock_absorber` rows.
- Exactly 65 rows, with `trial_id` and `attachment_id` unchanged from the template.
- The CSV is accompanied by `setup.jpg` and `platform.md`, and `platform.md` states the board mounting orientation.

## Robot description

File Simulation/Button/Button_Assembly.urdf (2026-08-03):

<?xml version='1.0' encoding='utf-8'?>
<robot name="Button_Assembly">
  <joint name="PrismaticJoint" type="prismatic">
    <origin xyz="-0. 0. -0." rpy="0. -0. -0." />
    <parent link="World" />
    <child link="button_pivot" />
    <axis xyz="1. 0. 0." />
    <limit lower="-0.01" upper="0." effort="100.0" velocity="1.0" />
  </joint>
  <joint name="RevoluteJoint" type="revolute">
    <origin xyz="-0.0034325 0.0304632 0. " rpy="0. 0.0000001 0. " />
    <parent link="World" />
    <child link="lid_pivot" />
    <axis xyz="0. 0. 1." />
    <limit lower="-1.5707963" upper="0.6981317" effort="100.0" velocity="10.0" />
  </joint>
  <link name="World">
    <inertial><origin xyz="0.000000 0.000000 0.010500" rpy="0 0 0" /><mass value="0.1412" /><inertia ixx="7.36627e-05" ixy="0" ixz="0" iyy="9.64878e-05" iyz="0" izz="0.000159776" /></inertial><visual>
      <origin xyz="-0.0209518 -0. 0. " rpy="0. 1.5707964 0. " />
      <geometry>
        <mesh filename="meshes/tn__corpo1_dC_Corpo1_Mesh.obj" scale="1. 1. 1." />
      </geometry>
    </visual>
    <collision>
      <origin xyz="-0.0209518 -0. 0. " rpy="0. 1.5707964 0. " />
      <geometry>
        <mesh filename="meshes/tn__corpo1_dC_Corpo1_Mesh.obj" scale="1. 1. 1." />
      </geometry>
    </collision>
  </link>
  <link name="button_pivot">
    <inertial><origin xyz="0.000000 0.000000 0.005700" rpy="0 0 0" /><mass value="0.0377" /><inertia ixx="7.44185e-06" ixy="0" ixz="0" iyy="7.44185e-06" iyz="0" izz="1.27119e-05" /></inertial><visual>
      <origin xyz="0. 0. 0." rpy="0. 1.5707964 0. " />
      <geometry>
        <mesh filename="meshes/tn__botao1_dC_Corpo1_Mesh.obj" scale="1. 1. 1." />
      </geometry>
    </visual>
    <collision>
      <origin xyz="0. 0. 0." rpy="0. 1.5707964 0. " />
      <geometry>
        <mesh filename="meshes/tn__botao1_dC_Corpo1_Mesh.obj" scale="1. 1. 1." />
      </geometry>
    </collision>
  </link>
  <link name="lid_pivot">
    <inertial><origin xyz="0.025000 0.024000 -0.008500" rpy="0 0 0" /><mass value="0.0824" /><inertia ixx="3.17707e-05" ixy="0" ixz="0" iyy="2.51761e-05" iyz="0" izz="4.9679e-05" /></inertial><visual>
      <origin xyz="0.0055156 0.0175212 -0.0249821" rpy="-1.5707964 -1.5707964 0. " />
      <geometry>
        <mesh filename="meshes/tn__Tampa1_dC_Corpo1_Mesh.obj" scale="1. 1. 1." />
      </geometry>
    </visual>
    <collision>
      <origin xyz="0.0055156 0.0175212 -0.0249821" rpy="-1.5707964 -1.5707964 0. " />
      <geometry>
        <mesh filename="meshes/tn__Tampa1_dC_Corpo1_Mesh.obj" scale="1. 1. 1." />
      </geometry>
    </collision>
  </link>
</robot>

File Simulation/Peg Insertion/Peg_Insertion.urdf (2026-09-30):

<?xml version="1.0"?>
<!--
  Peg insertion: five-hole plate + one threaded peg in the centre hole on a
  continuous revolute and a prismatic joint along the hole axis.
  Turns the plate normal to +X like the other mechanisms.
  PrismaticJoint = 0 seats the peg (its end flush with the plate back).
-->
<robot name="Peg_Insertion">
  <link name="World">
    <inertial><origin xyz="0.0075 0 0" rpy="0 0 0" /><mass value="0.1008" /><inertia ixx="0.000114125" ixy="0" ixz="0" iyy="6.7105e-05" iyz="0" izz="5.08014e-05" /></inertial>
    <visual>
      <origin xyz="0 0 0" rpy="0 1.5707963 0" />
      <geometry><mesh filename="meshes/Base_principal_Corpo1.obj" scale="1 1 1" /></geometry>
    </visual>
    <collision>
      <origin xyz="0.0075 0 0" rpy="0 0 0" />
      <geometry><box size="0.015 0.076 0.076" /></geometry>
    </collision>
  </link>
  <link name="rot_pivot">
    <inertial><origin xyz="0 0 0" rpy="0 0 0" /><mass value="0.005" /><inertia ixx="1e-06" ixy="0" ixz="0" iyy="1e-06" iyz="0" izz="1e-06" /></inertial>
  </link>
  <link name="peg">
    <!-- CAD mass is ~2 g; 20 g keeps the grasp contacts stable. -->
    <inertial><origin xyz="0 0 0.019" rpy="0 0 0" /><mass value="0.02" /><inertia ixx="1e-06" ixy="0" ixz="0" iyy="1e-06" iyz="0" izz="1e-06" /></inertial>
    <visual>
      <origin xyz="0 0 0" rpy="0 0 0" />
      <geometry><mesh filename="meshes/Al__a_Corpo1.obj" scale="1 1 1" /></geometry>
    </visual>
    <collision>
      <origin xyz="0 0 0" rpy="0 0 0" />
      <geometry><mesh filename="meshes/Al__a_Corpo1.obj" scale="1 1 1" /></geometry>
    </collision>
  </link>
  <!-- Child frames have +Z along the hole, which is World +X. -->
  <joint name="RevoluteJoint" type="continuous">
    <origin xyz="0 0 0" rpy="0 1.5707963 0" />
    <parent link="World" />
    <child link="rot_pivot" />
    <axis xyz="0 0 1" />
  </joint>
  <joint name="PrismaticJoint" type="prismatic">
    <origin xyz="0 0 0" rpy="0 0 0" />
    <parent link="rot_pivot" />
    <child link="peg" />
    <axis xyz="0 0 1" />
    <limit lower="0.0" upper="0.020" effort="100.0" velocity="1.0" />
  </joint>
</robot>

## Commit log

2026-05-27 Add button assembly and update Honeycomb and valve USD assets to keep light consistent across all assets. Flattened the Honeycomb_Panel and Honeycomb assets.
2026-05-29 Update Circuit Breaker Assembly asset, still under work
2026-06-02 Add Completed Circuit Breaker Assembly .usd asset
2026-06-10 Add USD assembly files for drawer and key
    Add new USD assembly definitions for the drawer and key components.
2026-06-16 Adding honeycomb small and medium size
    [Honeycomb_Panel_M.stl, Honeycomb_Panel_S.stl]
2026-06-29 Add Shock Absorber Assembly USD file to the repository. Updated M14 thread USD file.
2026-07-06 Update README.md
    Adding printing guide
2026-07-06 Add files via upload
    Adding updated assembly
2026-07-06 Delete Simulation/Shock Absorber/Shock_Absorber_Assembly.usd
    deleting old assembly
2026-07-09 Adding Lamp and M8 Thread simulation assets
2026-07-20 Revise protocol details and logging instructions
    Updated repository link and clarified temperature ranges. Added detailed failure cause vocabulary for trial logging.
2026-07-22 initial urdf
    [ball_valve.urdf, button.urdf, circuit_breaker.urdf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]
2026-07-22 v0 urdf
    [Ball_Valve.urdf, Base_Corpo1.obj, Button_Assembly.urdf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]
2026-07-30 Add High Torque Valve, Ball Valve Friction Ring Set, and Peg Insertion assets
2026-07-30 Restore Simulation/Shock Absorber/Shock_Absorber_Assembly.usd and move Simulation/Shock Absorber/Shock_Absorber_Assembly.usdz to CAD/Shock Absorber/Shock_Absorber_Assembly.usdz
2026-08-03 Relative path, velocity limits and inertia
    [Ball_Valve.urdf, Button_Assembly.urdf, Button_Assembly_robot.urdf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]
2026-08-03 remove duplicated urdf
    [ball_valve.urdf, button.urdf, small_valve.urdf]
2026-08-10 more urdfs
    [Al__a_Corpo1.obj, Ball_Valve_Friction_Ring_Set.urdf, Base_Corpo1.obj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]
2026-08-11 Fixed inertia
    [Ball_Valve_Friction_Ring_Set.urdf, Honeycomb.urdf]
2026-08-11 removed redundant urdf
    [Button_Assembly.urdf, Button_Assembly_robot.urdf, Button_Assembly_sensor.urdf]
2026-08-11 Move peg insertion simulation assets
    [Al__a_Corpo1.obj, Base_principal_Corpo1.obj, Peg_insertion_1.urdf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]
2026-08-11 Remove unused M14 assets
    [Base_Corpo1.obj, Cylinder.obj, M14.urdf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]
2026-08-12 Clarify peg insertion process in protocol
    Updated description for peg insertion process.
2026-08-12 Change image for torque-based tasks in README
    Updated image reference for torque-based tasks section.
2026-08-12 duplicated urdf
    [circuit_breaker.urdf]
2026-08-17 Revise physical setup and logging conventions in protocol
    Updated protocol for physical setup and trial logging conventions. Clarified attachment seating, logging details, and criteria for success.
2026-08-17 Update README with trial logging and attachment details
    Clarified the description of the Peg Insertion Plate and updated trial logging details.
2026-08-17 Update README with attachment categories section
    Added images and descriptions for attachment categories.
2026-08-31 Stabilize lamp collision for PhysX grasping.
    Replace CAD-shell convex hulls on lamp_pivot with two cylinders along
    the bulb axis, and scale the link mass to 0.20 kg so grasp contacts
    no longer explode.
    [Lamp_Assembly.urdf]
2026-09-07 Revise README for clarity and structure
    Updated the README.md to improve clarity and structure, including changes to project description, documentation links, and printing instructions.
2026-09-26 Add two-part ArUco cell with printing and assembly instructions
    [aruco_cell_assembly.obj, aruco_cell_base_white.obj, aruco_cell_marker_black.obj]
2026-09-26 Remove printed-cell photograph pending replacement
2026-09-26 Fix URDF articulation and collision geometry for M8, M30 and Peg Insertion
    - M8 Thread (M8_Assy.urdf): Replace base mesh collider with primitive box and cylinders to prevent single-convex-hull cone approximation from blocking gripper contact. Increase nut mass to 20 g to stabilize GPU PhysX grasp contacts, and structure continuous RevoluteJoint + PrismaticJoint along +X.
    - M30 Thread (M30.urdf): Align plate normal to +X consistent with the board and other mechanisms. Move prismatic joint to the nut (World -> rot_pivot -> Nut), and replace conical base mesh collider with box and cylinder primitives.
    - Peg Insertion (Peg_Insertion.urdf, Peg_insertion_1..5.urdf): Free the peg from static FixedJ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
    [M30.urdf, M8_Assy.urdf, Peg_Insertion.urdf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]
2026-09-30 Correct shock absorber task: move loose part onto pin
